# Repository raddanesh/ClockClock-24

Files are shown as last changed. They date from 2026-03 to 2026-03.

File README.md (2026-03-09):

# ClockClock-24

## LPC845-BRK usage in master and client firmware

This project uses the **NXP LPC845-BRK** as the main MCU platform for both firmware roles in the system. I kept a **single firmware codebase** and used compile-time configuration to switch the board behavior between **master** and **client** modes.

The [LPC845 breakout](https://www.nxp.com/design/design-center/development-boards-and-designs/LPC845-BRK) board provides a powerful and flexible development system for NXP's low end Cortex-M0+-based LPC84x Family of MCUs, delivered in an ultra-low-cost evaluation board. 

This breakout board can be used with a range of development tools, including the MCUXpresso IDE toolchain. The LPCXpresso845 Breakout board is developed by NXP to enable evaluation of and prototyping with the LPC84x family of MCUs.

<p align="center">
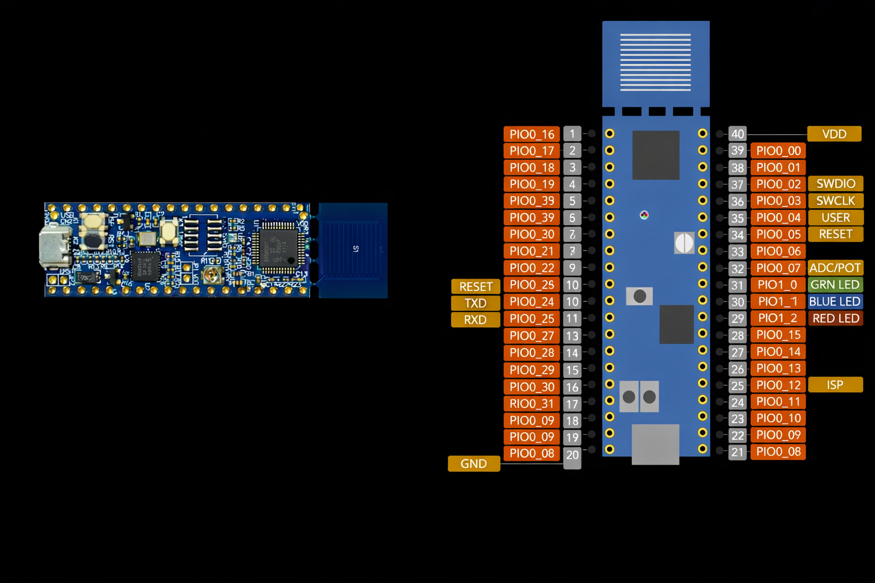
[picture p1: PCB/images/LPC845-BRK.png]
LPC845-BRK
  
</p>

The LPC845 breakout board features an on-board CMSIS-DAP debug and VCOM port, RGB user LEDs, capacitive touch button, user potentiometer and allows an easy prototyping experience with access to 38 LPC845 port pins.

The role selection is controlled through `PL_CONFIG_IS_MASTER` in `platform.h`:

- `PL_CONFIG_IS_MASTER = 1` builds the **master**
- `PL_CONFIG_IS_MASTER = 0` builds the **client**

This approach keeps the low-level platform code shared while allowing each build to enable only the modules needed for its role.

### Why LPC845-BRK

I used the LPC845-BRK because it provides the peripherals needed for this project in a compact Cortex-M0+ platform:

- enough GPIO for stepper-driver control lines and magnetic sensor inputs
- multiple USARTs for separating debug/shell communication from the RS-485 bus
- SCTimer support for motion timing
- internal flash for non-volatile configuration storage
- straightforward integration with the MCUXpresso SDK

The project follows the normal MCUXpresso startup flow:

- `BOARD_InitBootPins()`
- `BOARD_InitBootClocks()`
- `BOARD_InitBootPeripherals()`

After board startup, the firmware enters `APP_Run()`, initializes the platform in `PL_Init()`, and starts FreeRTOS.

### Shared LPC845 platform layer

Both master and client firmware use the same base initialization code in `platform.c`. In `PL_Init()`, the LPC845 initializes the shared system modules, including:

- MCU utility library
- FreeRTOS
- GPIO support
- optional shell/debug UART
- X12.017 stepper driver interface
- stepper control layer
- magnet sensor layer
- RS-485 communication
- non-volatile memory (`nvmc`)
- matrix logic

This gives both firmware roles the same hardware abstraction and startup flow, while feature selection is handled by configuration.

### LPC845-BRK in the master module

In **master mode**, the LPC845 is used as the **system coordinator**. Its job is not to drive the motors directly, but to manage the logical clock matrix and send commands to client boards.

The master firmware is responsible for:

- maintaining the logical matrix state
- converting digits and animations into hand target positions
- sending commands to client boards over **RS-485**
- providing a shell/debug interface over **USART0**

#### Master communication usage

On the master, I used:

- **USART0** for the local shell/debug console
- **USART2** for the RS-485 bus

This allows the master board to stay connected to a PC for debugging or manual commands while also controlling the distributed client nodes.

The shell is enabled only in master mode, so the LPC845 acts as both the local command interface and the RS-485 network controller.

#### Master logic role

The main master logic is implemented in `matrixMaster.c`. In this mode, the LPC845:

- stores the current matrix state
- maps clocks to board addresses and positions
- generates patterns for digits and animations
- forwards movement commands to the correct client board

So in the master build, the LPC845-BRK is mainly used as a **central controller and communication node**.

### LPC845-BRK in the client module

In **client mode**, the LPC845 is used as the **real-time motor-control MCU** for one physical board.

The client firmware is responsible for:

- controlling the local X12.017 driver ICs
- driving all local clock motors
- reading Hall/magnetic sensors for homing
- zeroing and calibrating the hands
- storing local calibration and address data in flash
- receiving commands from the master over **RS-485**

#### Client communication usage

On the client, the LPC845 uses **USART2** for RS-485 communication. Unlike the master, the client does not need the shell/debug console and focuses only on bus-controlled operation.

One useful LPC845 feature I used here is its **hardware-assisted RS-485 direction control**. Instead of manually toggling a GPIO for transmit/receive switching, the firmware uses the USART RTS output as the **RS485_TXRX_EN** signal.

In this design:

- `USART2_TXD` -> `P1_2`
- `USART2_RXD` -> `P1_0`
- `USART2_RTS` -> `P1_1`

This simplifies half-duplex RS-485 handling and reduces timing issues in the communication layer.

#### Client motion-control role

The client-side implementation is mainly in:

- `matrixClient.c`
- `stepper.c`
- `StepperBoard.c`

In this mode, the LPC845 directly controls the board hardware by:

- managing the local 12 motors
- generating step and direction signals for the X12.017 drivers
- using the **SCTimer** for motion timing
- reading magnet sensors to find repeatable zero positions
- applying stored offsets and backlash compensation

So in the client build, the LPC845-BRK is the actual **embedded motion-control node**.

### Internal flash usage

I also used the LPC845 internal flash to store persistent board-specific settings through the `nvmc` module. A reserved flash page is used for non-volatile configuration such as:

- RS-485 board address
- per-stepper zero offsets
- backlash compensation values

This allows each client board to keep its calibration and address after reset or power loss.

### Summary

The LPC845-BRK is used in two different roles in this project:

- In the **master**, it acts as the matrix controller, animation engine, shell host, and RS-485 command source.
- In the **client**, it acts as the real-time motor controller, handling X12.017 stepper driving, sensor-based homing, and local calibration storage.

Using the same LPC845 platform and shared codebase for both roles made the firmware easier to maintain while still allowing each build to specialize for its intended function.

<div align="center">
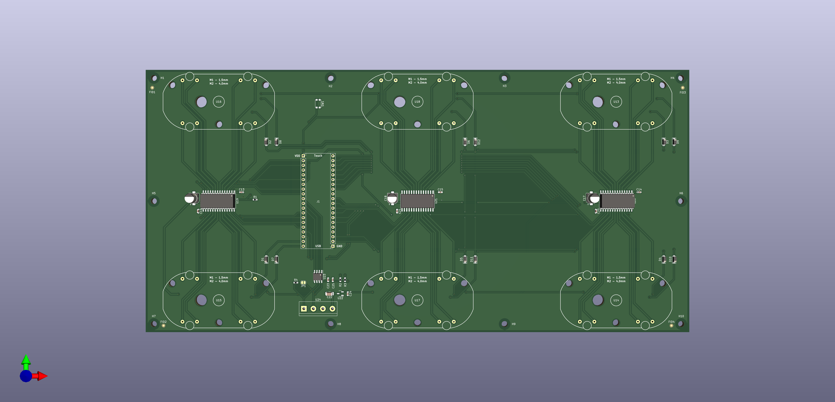
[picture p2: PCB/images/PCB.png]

</div>

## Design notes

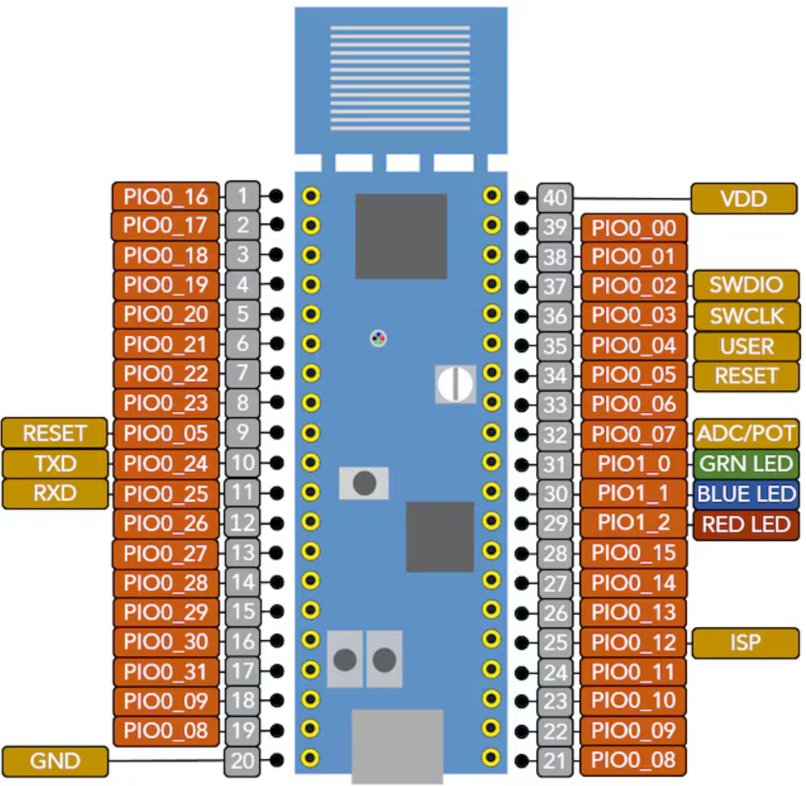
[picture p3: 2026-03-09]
PCB/images/LPC845-BRK-BD2.png

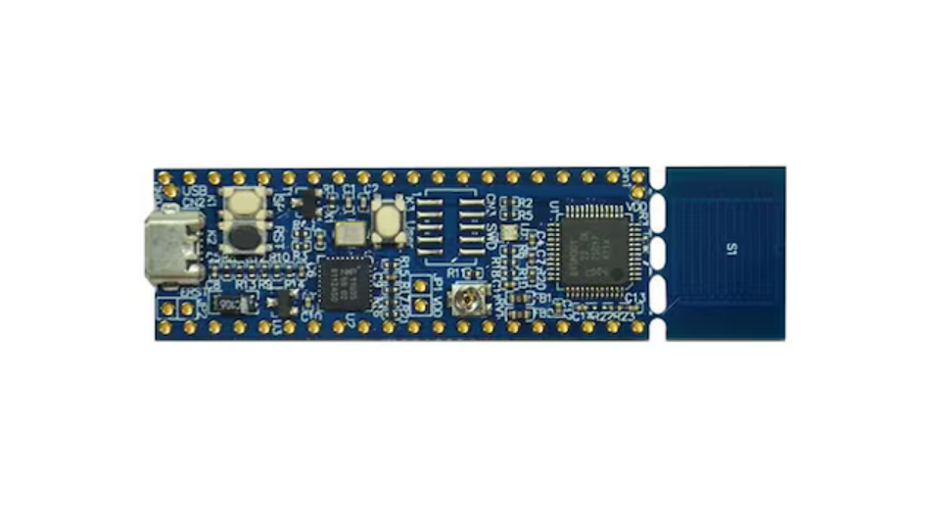
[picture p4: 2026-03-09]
PCB/images/LPC845-BRK-1.png

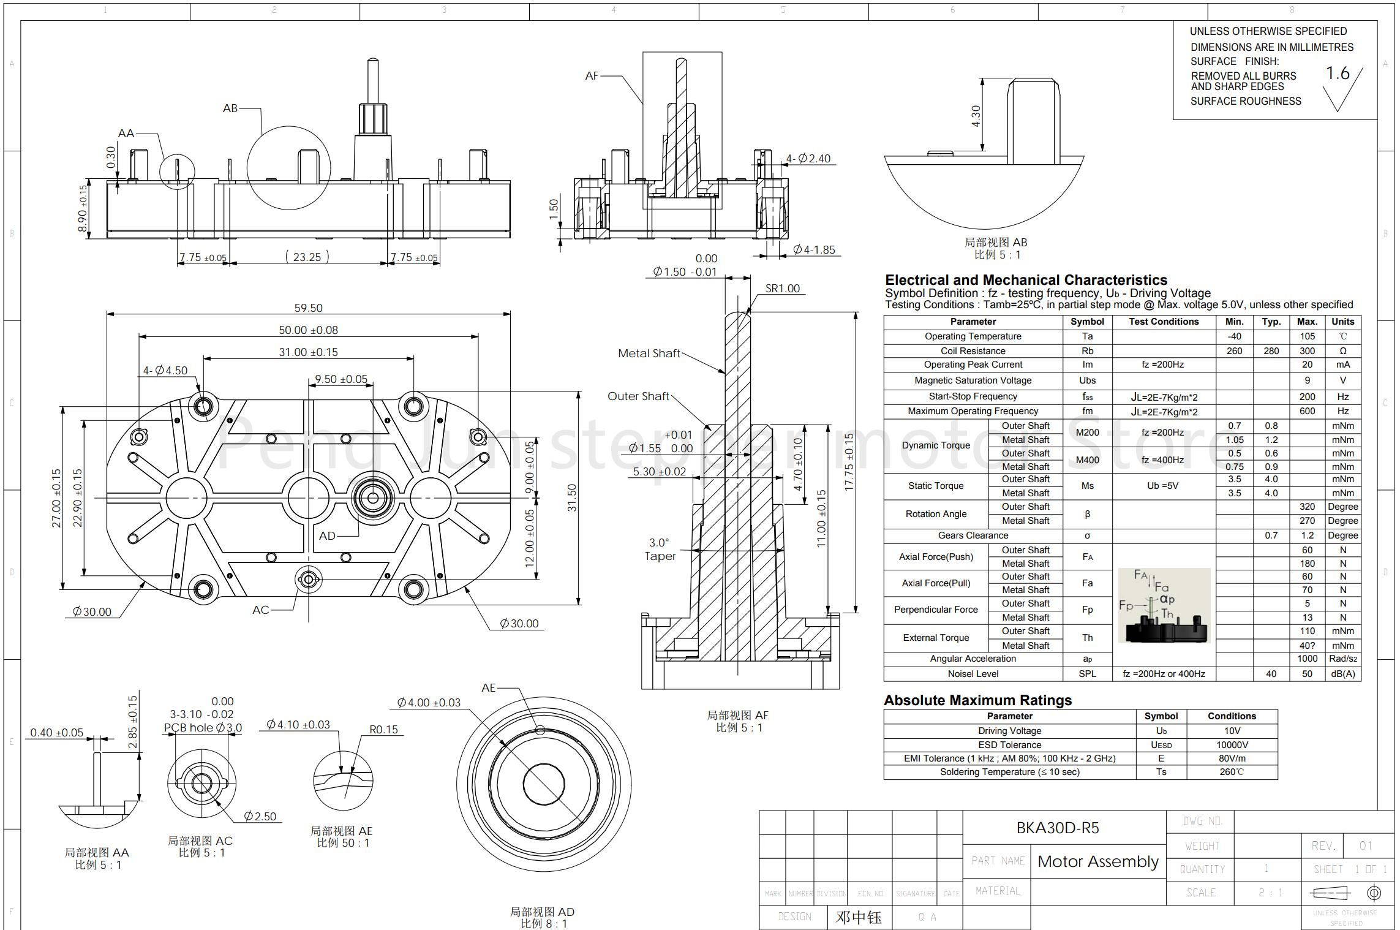
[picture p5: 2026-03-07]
PCB/BKA30D-R5/BKA30D-R5.jpg

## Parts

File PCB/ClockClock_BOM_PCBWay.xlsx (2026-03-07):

 |  |  | W520148AS1V2_PCS BOM (Bill of Materials)
Item # | *Ref Des | *Qty | Manufacturer | *Mfg Part # | Description / Value | *Package/Footprint | Type | Your Instructions / Notes | Source
1 | U19, U20, U21 | 3 | Switec | AX1201728SG | M-S Quad Driver X12.017 | SOL28 | SMD |  | Chip-IC Store: https://www.aliexpress.com/item/32596665175.html?spm=a2g0s.9042311.0.0.22e44c4d84lpPX
2 | U23 | 1 | Texas Instruments | SN65HVD75DR | SN65HVD75 | 8-Pin SOIC | SMD |  | Mouser #: 595-SN65HVD75DR
3 | U1, U2, U3, U4, U5, U6, U7, U8, U9, U10, U11, U12 | 12 | Diodes Incorporated | AH1913-W-7 | AH1913 | SC59-3 | SMD |  | Mouser #: 621-AH1913-W-7
4 | U22 | 1 | Torex Semiconductor | XC6206P332MR-G | XC6206-3.3V | SOT-23-3 | SMD |  | Mouser #: 865-XC6206P332MR-G
5 | U24 | 1 | TE Connectivity | 282836-2 | Fixed Terminal Blocks 5.0MM PCB MOUNT 2P | THT | thru-hole | Do not populate (DNP) | Mouser #: 571-2828362
6 | U13, U14, U15, U16, U17, U18 | 6 | Peng Chun Electronics | BKA30D-R5 360 degrees | VID28 Dual-Shaft Stepper Motor 360 degree | THT | thru-hole | Do not populate (DNP) | Pen Chung Electronics: https://www.aliexpress.com/item/32832881189.html?spm=a2g0s.9042311.0.0.22e44c4d84lpPX
7 | J1 | 1 | Harwin | M20-7822046 | LPC845-BRK socket | THT | thru-hole | Do not populate (DNP) | Mouser #: 855-M20-7822046
8 | C1, C2, C3, C4, C5, C6, C7, C8, C9, C10, C11, C12, C13, C14, C15, C19, C20, C21, C23 | 19 | ATC | 0603X7R104JT1AT | 100nF Ceramic, 25V | 0603 | SMD | Can be any ceramic 25V | Mouser #: 581-0603X7R104JT1AT
9 | C16, C17, C18 | 3 | Panasonic | EEE-1CA220SR | 22uF/16V Electrolyt | 5x5.5x5.4mm | SMD |  | Mouser #: 667-EEE-1CA220SR
10 | C24, C25 | 2 | Kemet | C0603C105K4PAC7411 | 1uF Ceramic, 16V | 0603 | SMD | Can be any ceramic 25V | Mouser #: 80-C0603C105K4PLR
11 | C22 | 1 | AVX | F9H1C106KAA | 10uF/16V Tantalum | 1206 | SMD | Can be any Tantalum >12V | Mouser #: 581-F9H1C106KAA
12 | R1, R2, R3 | 3 | Yageo | RT0603WRE0710KL | 10k Ohm 0.5% | 0603 | SMD | Can be any generic resistor 0.5% | Mouser #: 603-RT0603WRE0710KL
13 | R4 | 1 | Yageo | RT0603DRE07120RL | 120 Ohm 0.5% | 0603 | SMD | Can be any generic resistor 0.5% | Mouser #: 603-RT0603DRE07120RL
14 | D1, D2, D3, D4, D5, D6, D7, D8, D9, D10, D11, D12 | 12 | onsemi | MMSD4148T1G | General Purpose, Power, Switching 100V 200mA | SOD-123-2 | SMD |  | Mouser #: 863-MMSD4148T1G
15 | SW1 | 1 | C&K | KMR221GLFS | KMKR221G-LFS SPST Switch | 4.6x2.8x1.9mm | SMD |  | Mouser #: 611-KMR221G-LFS
Need a quick and accurante quote? Need an efficient production? Please read SMT Ordering Necessary Files & Info in 1 minute. Thank you very much! (https://www.pcbway.com/smt_ordering_guide.html)
Click for Instructions on How to Create a BOM (https://www.pcbway.com/blog/PCB_Assembly/How_to_Build_a_BOM__Bill_Of_Materials_.html)

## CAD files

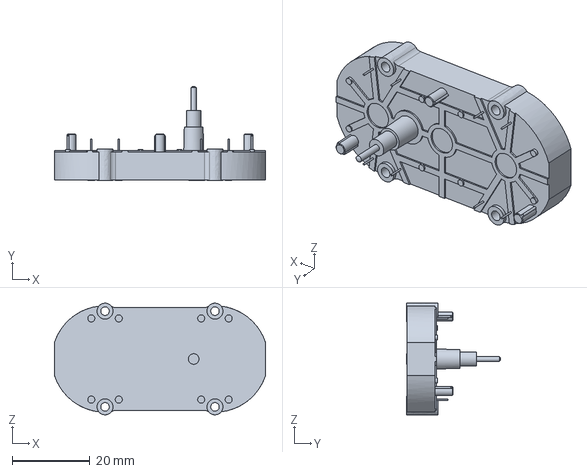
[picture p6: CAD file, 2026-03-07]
PCB/BKA30D-R5/Bka30D-R5.step
54.3 x 24.2 x 28.8 mm

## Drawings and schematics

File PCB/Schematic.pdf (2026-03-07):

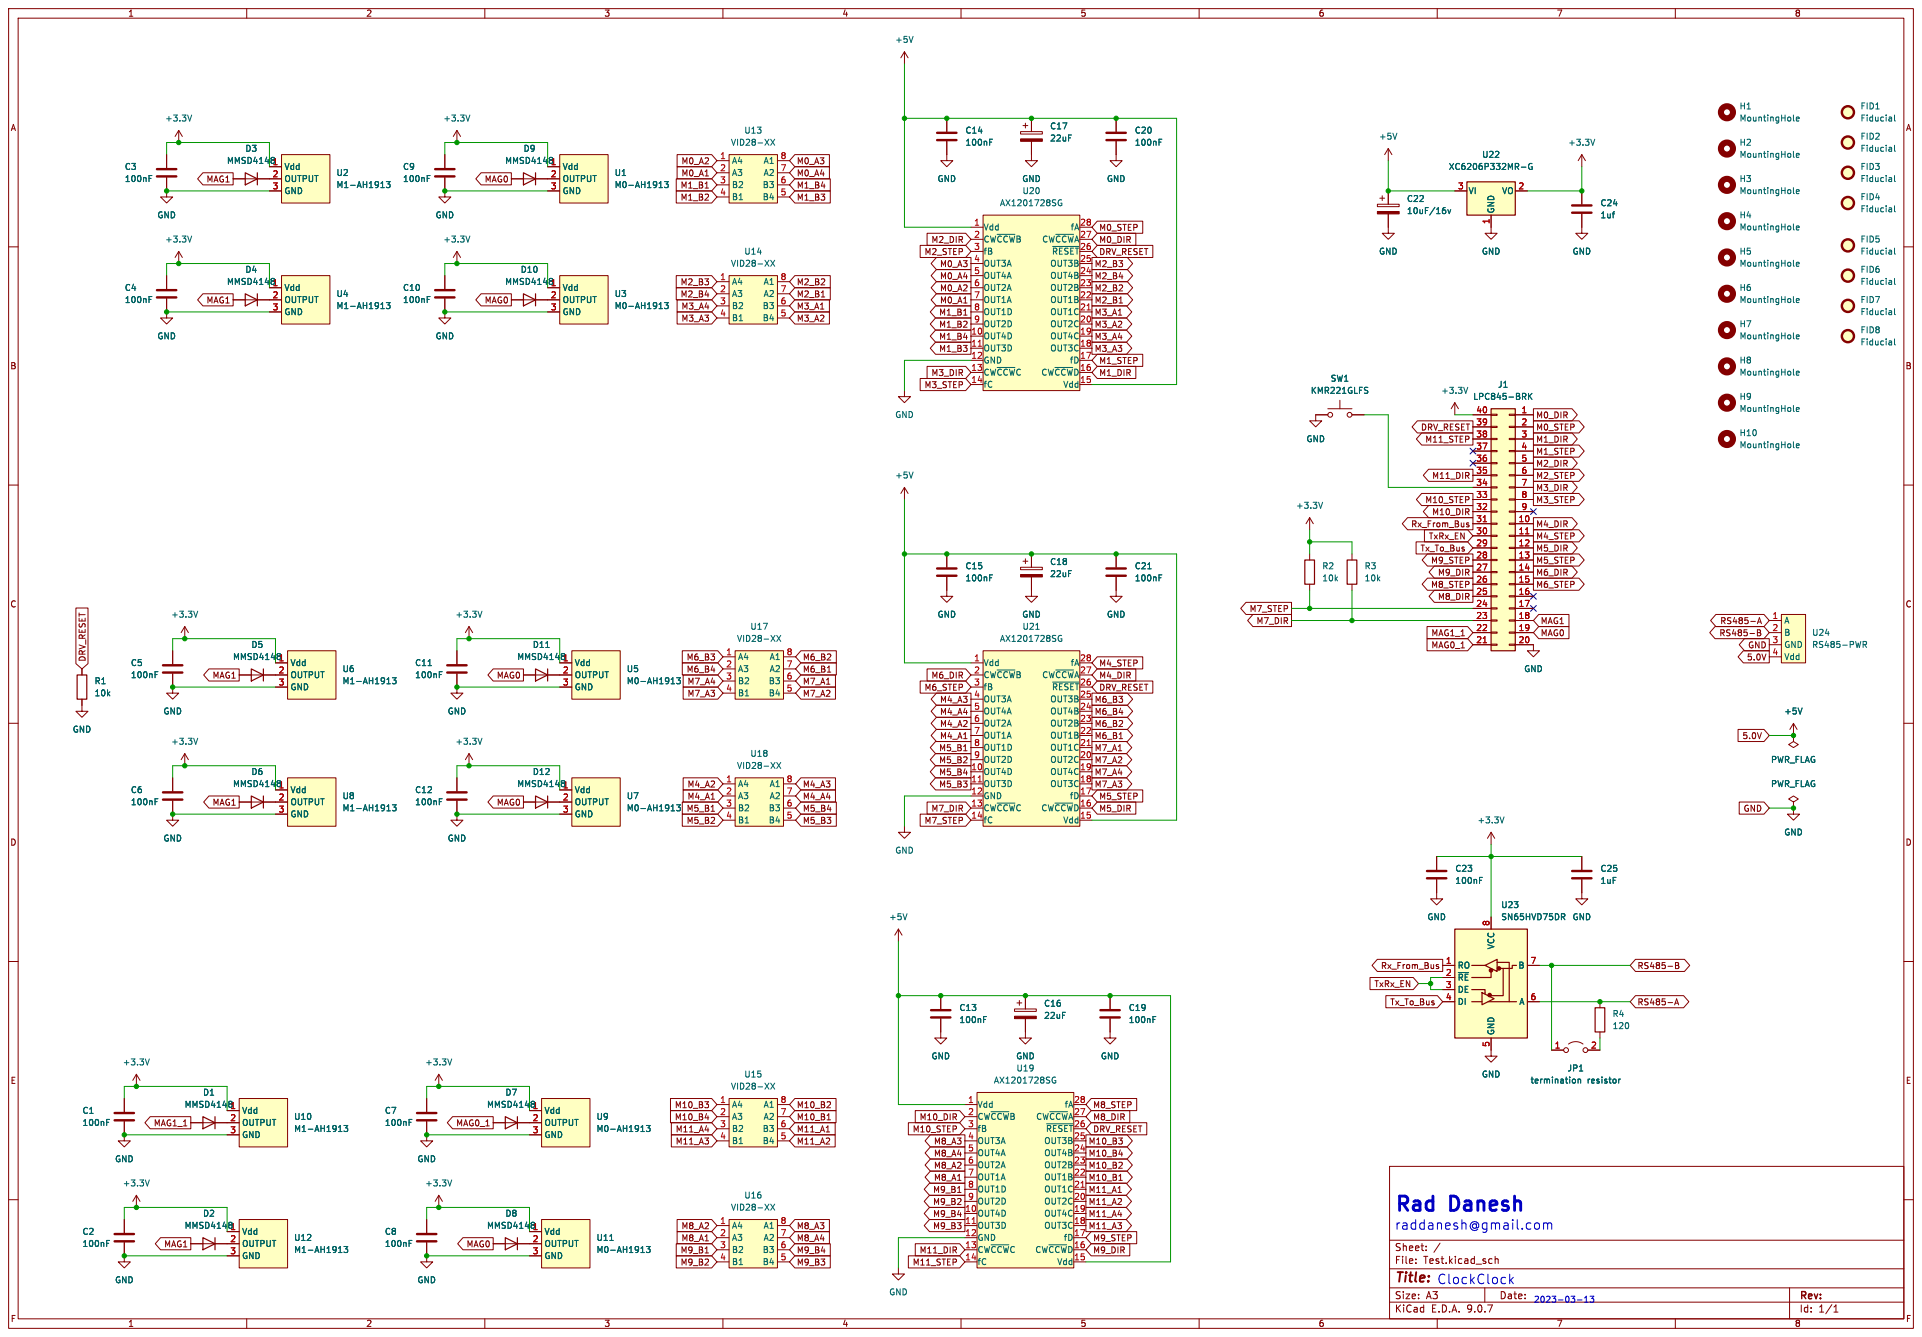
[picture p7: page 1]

fD 17 CW~{CCW}D16 Vdd 15 U20 AX1201728SG

FID2 Fiducial FID3 Fiducial FID7 Fiducial FID6 Fiducial GND

fA 28 CW~{CCW}A27 ~{RESET} 26 OUT3B 25 OUT4B 24 OUT2B 23 OUT1B 22 OUT1C 21 OUT2C 20 OUT4C 19 OUT3C 18

fB 3 OUT3A 4 OUT4A 5 OUT2A 6 OUT1A 7 OUT1D 8 OUT2D 9 OUT4D 10 OUT3D 11 GND 12 CW~{CCW}C 13

fD 17 CW~{CCW}D16 Vdd 15 U21 AX1201728SG

fD 17 CW~{CCW}D16 Vdd 15 U19 AX1201728SG

Id: 1/1 Title: File: Test.kicad_sch Sheet: /

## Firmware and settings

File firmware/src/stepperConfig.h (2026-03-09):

#ifndef STEPPERCONFIG_H_
#define STEPPERCONFIG_H_

#include "McuLibconfig.h"

#include "platform.h"
#define STEPPER_CONFIG_IS_LED_RING  (PL_CONFIG_USE_STEPPER_EMUL) /* temporary only */

#define STEPPER_CLOCK_360_STEPS   (4320) /* number of steps for 360 degrees */

/* time for a full round */
#define STEPPER_TIME_360_DEGREE_MS  (3000)
/* period needed for a single step in microseconds */
#define STEPPER_TIME_STEP_US        ((STEPPER_TIME_360_DEGREE_MS*1000U)/STEPPER_CLOCK_360_STEPS)
/* steps per second */
#define STEPPER_STEPS_PER_SEC							((STEPPER_CLOCK_360_STEPS*1000U)/STEPPER_TIME_360_DEGREE_MS)

#ifndef STEPPER_CONFIG_USE_FREERTOS_HEAP
  #define STEPPER_CONFIG_USE_FREERTOS_HEAP   (McuLib_CONFIG_SDK_USE_FREERTOS)
    /*!< 1: use FreeRTOS Heap (default), 0: use stdlib malloc() and free() */
#endif

#endif /* STEPPERCONFIG_H_ */

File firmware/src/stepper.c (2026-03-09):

#include "platform.h"
#include "stepperConfig.h"
#include "stepper.h"
#if PL_CONFIG_USE_X12_STEPPER
  #include "McuX12_017.h"
#endif
#if PL_CONFIG_USE_WDT
  #include "watchdog.h"
#endif
#include "McuRTOS.h"
#include "McuUtility.h"
#include "McuWait.h"
#include "Shell.h"
#include "matrix.h"
#include "fsl_ctimer.h"
#include "fsl_sctimer.h"
#include "StepperBoard.h"
#include "McuCriticalSection.h"

#define STEPPER_CMD_QUEUE_LENGTH    (8) /* maximum number of items in stepper command queue */
/* the degree of the move at the beginning and end which is used for acceleration and de-acceleration */
#define STEPPER_ACCELERATION_RANGE_DEGREE   (25)
#define STEPS_TO_DEGREE(steps)              (((steps)*360u)/STEPPER_CLOCK_360_STEPS)

#define STEPPER_START_TIMER()        SCTIMER_StartTimer(SCT0, kSCTIMER_Counter_U)
#define STEPPER_STOP_TIMER()         SCTIMER_StopTimer(SCT0, kSCTIMER_Counter_U)

typedef enum {
  SCT_CHANNEL_MASK_0 = (1<<0),
  SCT_CHANNEL_MASK_1 = (1<<1),
  SCT_CHANNEL_MASK_2 = (1<<2),
  SCT_CHANNEL_MASK_3 = (1<<3),
  SCT_CHANNEL_MASK_4 = (1<<4),
  SCT_CHANNEL_MASK_5 = (1<<5),
  SCT_CHANNEL_MASK_6 = (1<<6),
  SCT_CHANNEL_MASK_7 = (1<<7)
} SCT_CHANNEL_MASK_e;

/* default configuration, used for initializing the config */
static const STEPPER_Config_t defaultConfig =
{
  .device = NULL, /* motor or LED device */
  .stepFn = NULL, /* callback to increment or decrement steps */
  .getBacklashFn = NULL,
};

/* device for a single LED ring */
typedef struct {
  void *device; /* point to the actual motor device */
  void (*stepFn)(void *device, int step); /* function pointer to perform a single step forward (1) or backward (-1) */
  int32_t (*getBacklashFn)(void *device, Coord_t coord, int steps); /* function pointer to get backlash steps */
  int32_t lastBacklashMove;
  int32_t degree; /* current degree */
  int32_t pos; /* current position */
  int32_t doSteps; /* != 0: steps to do */
  int16_t delay; /* shortest delay: 0 */
  int16_t delayCntr; /* in the range of delay..0, step will be done at counter of 0 */
  int32_t accelStepCntr; /* current counter of steps since start */
  bool speedup, slowdown;
  Coord_t coord;
  QueueHandle_t queue; /* queue for the motor */
} STEPPER_Device_t;

void STEPPER_GetDefaultConfig(STEPPER_Config_t *config) {
  memcpy(config, &defaultConfig, sizeof(*config));
}

STEPPER_Handle_t STEPPER_DeinitDevice(STEPPER_Handle_t device) {
#if STEPPER_CONFIG_USE_FREERTOS_HEAP
  vPortFree(device);
#else
  free(device);
#endif
  return NULL;
}

STEPPER_Handle_t STEPPER_InitDevice(STEPPER_Config_t *config) {
  STEPPER_Device_t *handle;

#if STEPPER_CONFIG_USE_FREERTOS_HEAP
  handle = (STEPPER_Device_t*)pvPortMalloc(sizeof(STEPPER_Device_t)); /* get a new device descriptor */
#else
  handle = (STEPPER_Device_t*)malloc(sizeof(STEPPER_Device_t)); /* get a new device descriptor */
#endif
  assert(handle!=NULL);
  if (handle!=NULL) { /* if malloc failed, will return NULL pointer */
    memset(handle, 0, sizeof(STEPPER_Device_t)); /* init all fields */
    handle->device = config->device;
    handle->stepFn = config->stepFn;
    handle->getBacklashFn = config->getBacklashFn;
    handle->degree = 0;
    handle->pos = 0;
    handle->doSteps = 0;
    handle->delay = 0;
    handle->delayCntr = 0;
    handle->speedup = false;
    handle->slowdown = false;
    handle->coord = config->coord;
    handle->queue = xQueueCreate(STEPPER_CMD_QUEUE_LENGTH, sizeof(uint8_t*));
    if (handle->queue==NULL) {
      for(;;){} /* out of memory? */
    }
    vQueueAddToRegistry(handle->queue, "Squeue");
  }
  return handle;
}

void STEPPER_StopTimer(void) {
  STEPPER_STOP_TIMER();
}

void STEPPER_StartTimer(void) {
  STEPPER_START_TIMER();
}

#define STEP_SIZE  (1)

static void AccelDelay(STEPPER_Device_t *dev, int32_t degree) {
  /* this defines the acceleration/de-acceleration ramp depending on the step counter (at the beginning or at the end)
   * The delayCntr will be increased to have a slow start with a slow end.
   */
  if (degree<=STEPPER_ACCELERATION_RANGE_DEGREE) {
    if (degree<=2) {
      dev->delayCntr += 10;
    } else if (degree<=5) {
      dev->delayCntr += 7;
    } else if (degree<=10) {
      dev->delayCntr += 5;
    } else if (degree<=15) {
      dev->delayCntr += 3;
    } else if (degree<=STEPPER_ACCELERATION_RANGE_DEGREE) {
      dev->delayCntr += 1;
    }
  }
}

bool STEPPER_IsIdle(STEPPER_Handle_t stepper) {
  STEPPER_Device_t *mot = (STEPPER_Device_t*)stepper;
  return mot->doSteps==0;
}

bool STEPPER_TimerClockCallback(STEPPER_Handle_t stepper) {
  STEPPER_Device_t *mot = (STEPPER_Device_t*)stepper;
  int n;

  if (mot->doSteps==0) {
    return false; /* no work to do */
  }
  if (mot->delayCntr!=0) { /* delay going on? */
    mot->delayCntr -= STEP_SIZE; /* decrement delay counter */
    return true; /* still work go do */
  }
  /* do the step */
  if (mot->doSteps > 0) { /* forward */
    n = STEP_SIZE; /* number of steps in one iteration */
  } else { /* backward */
    n = -STEP_SIZE;
  }
  mot->pos += n; /* update position */
  if (mot->stepFn!=NULL) { /* call driver */
    mot->stepFn(mot->device, n);
  }
  mot->doSteps -= n; /* update remaining steps */
  mot->delayCntr = mot->delay*STEP_SIZE; /* reload delay counter */

  /* check if we have to speed up or slow down */
  if (mot->speedup || mot->slowdown) {
    int32_t stepsToGo; /* where we are in the sequence */

    stepsToGo = mot->doSteps;
    if (stepsToGo<0) { /* make it positive */
      stepsToGo = -stepsToGo;
    }
    if (mot->speedup && STEPS_TO_DEGREE(stepsToGo)>STEPPER_ACCELERATION_RANGE_DEGREE) { /* accelerate if we are starting up */
      if (STEPS_TO_DEGREE(mot->accelStepCntr)<=STEPPER_ACCELERATION_RANGE_DEGREE) {
        mot->accelStepCntr += STEP_SIZE; /* increase acceleration step counter position up to the cap value */
      }
      AccelDelay(mot, STEPS_TO_DEGREE(mot->accelStepCntr));
    } else if (mot->slowdown && STEPS_TO_DEGREE(stepsToGo)<STEPPER_ACCELERATION_RANGE_DEGREE) { /* slow down at the end */
      if (mot->accelStepCntr>=0) {
        mot->accelStepCntr -= STEP_SIZE; /* decrease the current de-accleration counter down to zero */
      }
      AccelDelay(mot, STEPS_TO_DEGREE(mot->accelStepCntr));
    }
  } /* speed up or slow down */
  return true; /* still work to do */
}

static void SCTIMER_Handler0(void) {
  uint32_t flags;

  flags = SCTIMER_GetStatusFlags(SCT0);
  if (flags & SCT_CHANNEL_MASK_0) {
    SCTIMER_ClearStatusFlags(SCT0, SCT_CHANNEL_MASK_0); /* Clear interrupt flag */
    MATRIX_TimerCallback();
  }
}
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

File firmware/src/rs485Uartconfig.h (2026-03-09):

#ifndef RS485UARTCONFIG_H_
#define RS485UARTCONFIG_H_

#include "fsl_usart.h"
#include "platform.h"

#define RS485Uart_CONFIG_USE_HW_OE_RTS  (1)  /* 1: Use e.g. on LPC845 OESEL (Output Enable Selection) feature. Note that the pin has to be configured in the PinMuxing as RTS! */

/* UART configuration items */
#define RS485Uart_CONFIG_UART_DEVICE                   USART2
#define RS485Uart_CONFIG_UART_SET_UART_CLOCK()         CLOCK_Select(kUART2_Clk_From_MainClk) /* Select the main clock as source clock of USART0. */
#define RS485Uart_CONFIG_UART_WRITE_BLOCKING           USART_WriteBlocking
#define RS485Uart_CONFIG_UART_GET_FLAGS                USART_GetStatusFlags
#define RS485Uart_CONFIG_UART_HW_RX_READY_FLAGS        (kUSART_RxReady|kUSART_HardwareOverrunFlag)
#define RS485Uart_CONFIG_UART_READ_BYTE                USART_ReadByte
#define RS485Uart_CONFIG_UART_CONFIG_STRUCT            usart_config_t
#define RS485Uart_CONFIG_UART_GET_DEFAULT_CONFIG       USART_GetDefaultConfig
#define RS485Uart_CONFIG_UART_ENABLE_INTERRUPTS        USART_EnableInterrupts
#define RS485Uart_CONFIG_UART_ENABLE_INTERRUPT_FLAGS   (kUSART_RxReadyInterruptEnable | kUSART_HardwareOverRunInterruptEnable)
#define RS485Uart_CONFIG_UART_IRQ_NUMBER               USART2_IRQn
#define RS485Uart_CONFIG_UART_INIT                     USART_Init
#define RS485Uart_CONFIG_UART_GET_CLOCK_FREQ_SELECT    kCLOCK_MainClk
#define RS485Uart_CONFIG_UART_IRQ_HANDLER              USART2_IRQHandler
#define RS485Uart_CONFIG_CLEAR_STATUS_FLAGS            USART_ClearStatusFlags

#if McuLib_CONFIG_CPU_IS_LPC  /* LPC845-BRK */
  #define RS485Uart_CONFIG_HAS_FIFO  (0)
#endif

#ifndef RS485Uart_CONFIG_UART_RX_QUEUE_LENGTH
  #if PL_CONFIG_IS_MASTER
    #define RS485Uart_CONFIG_UART_RX_QUEUE_LENGTH        (2*1024)
  #elif PL_CONFIG_IS_CLIENT
    #define RS485Uart_CONFIG_UART_RX_QUEUE_LENGTH        (128)
  #endif
  #define RS485Uart_CONFIG_UART_RESPONSE_QUEUE_LENGTH    (128)
#endif

#ifndef RS485Uart_CONFIG_UART_BAUDRATE
  #define RS485Uart_CONFIG_UART_BAUDRATE           115200
#endif

#endif /* RS485UARTCONFIG_H_ */

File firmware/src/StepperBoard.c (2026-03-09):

#include "StepperBoardConfig.h"
#include "StepperBoard.h"
#include "stepper.h"
#include <stddef.h>
#include <string.h>
#include <assert.h>
#if STEPBOARD_CONFIG_USE_FREERTOS_HEAP
  #include "McuRTOS.h"
#endif
#if PL_CONFIG_USE_WDT
  #include "watchdog.h"
#endif

typedef struct {
  uint8_t addr;
  bool enabled;
  STEPPER_Handle_t stepper[STEPBOARD_NOF_CLOCKS][STEPPER_NOF_CLOCK_MOTORS];
} STEPBOARD_Device_t;

/* default configuration, used for initializing the configuration */
static const STEPBOARD_Config_t defaultConfig =
{
  .addr = 0x0, .enabled = true,
  .stepper[0][0] = NULL, .stepper[0][1] = NULL,
  .stepper[1][0] = NULL, .stepper[1][1] = NULL,
  .stepper[2][0] = NULL, .stepper[2][1] = NULL,
  .stepper[3][0] = NULL, .stepper[3][1] = NULL,
	.stepper[4][0] = NULL, .stepper[4][1] = NULL,
	.stepper[5][0] = NULL, .stepper[5][1] = NULL,
};

void STEPBOARD_GetDefaultConfig(STEPBOARD_Config_t *config) {
  memcpy(config, &defaultConfig, sizeof(*config));
}

STEPBOARD_Handle_t STEPBOARD_InitDevice(STEPBOARD_Config_t *config) {
  STEPBOARD_Device_t *handle;

#if STEPBOARD_CONFIG_USE_FREERTOS_HEAP
  handle = (STEPBOARD_Device_t*)pvPortMalloc(sizeof(STEPBOARD_Device_t)); /* get a new device descriptor */
#else
  handle = (STEPBOARD_Device_t*)malloc(sizeof(STEPBOARD_Device_t)); /* get a new device descriptor */
#endif
  assert(handle!=NULL);
  if (handle!=NULL) { /* if malloc failed, will return NULL pointer */
    memset(handle, 0, sizeof(STEPBOARD_Device_t)); /* init all fields */
    handle->addr = config->addr;
    handle->enabled = config->enabled;
    handle->stepper[0][0] = config->stepper[0][0];
    handle->stepper[0][1] = config->stepper[0][1];
    handle->stepper[1][0] = config->stepper[1][0];
    handle->stepper[1][1] = config->stepper[1][1];
    handle->stepper[2][0] = config->stepper[2][0];
    handle->stepper[2][1] = config->stepper[2][1];
    handle->stepper[3][0] = config->stepper[3][0];
    handle->stepper[3][1] = config->stepper[3][1];
    handle->stepper[4][0] = config->stepper[4][0];
    handle->stepper[4][1] = config->stepper[4][1];
    handle->stepper[5][0] = config->stepper[5][0];
    handle->stepper[5][1] = config->stepper[5][1];
  }
  return handle;
}

uint8_t STEPBOARD_GetAddress(STEPBOARD_Handle_t board) {
  STEPBOARD_Device_t *handle = (STEPBOARD_Device_t*)board;
  return handle->addr;
}

bool STEPBOARD_IsEnabled(STEPBOARD_Handle_t board) {
  STEPBOARD_Device_t *handle = (STEPBOARD_Device_t*)board;
  return handle->enabled;
}

STEPPER_Handle_t STEPBOARD_GetStepper(STEPBOARD_Handle_t board, int clock, int motor) {
  STEPBOARD_Device_t *handle = (STEPBOARD_Device_t*)board;
  return handle->stepper[clock][motor];
}

bool STEPBOARD_ItemsInQueue(STEPBOARD_Handle_t board) {
  STEPBOARD_Device_t *handle = (STEPBOARD_Device_t*)board;
  QueueHandle_t queue;

  for(int i=0; i<STEPBOARD_NOF_CLOCKS; i++) {
    for(int j=0; j<STEPPER_NOF_CLOCK_MOTORS; j++) {
      queue = STEPPER_GetQueue(handle->stepper[i][j]);
      if (uxQueueMessagesWaiting(queue)!=0) { /* still things queued up? */
        return true; /* yes */
      }
    }
  }
  return false; /* nothing in queues */
}

bool STEPBOARD_IsIdle(STEPBOARD_Handle_t board) {
  STEPBOARD_Device_t *handle = (STEPBOARD_Device_t*)board;

  for(int i=0; i<STEPBOARD_NOF_CLOCKS; i++) {
    for(int j=0; j<STEPPER_NOF_CLOCK_MOTORS; j++) {
      if (!STEPPER_IsIdle(handle->stepper[i][j])) { /* still steps to do? */
        return false; /* yes, not finished */
      }
    }
  }
  return true; /* finished */
}

void STEPBOARD_NormalizePosition(STEPBOARD_Handle_t board) {
  STEPBOARD_Device_t *handle = (STEPBOARD_Device_t*)board;

  for(int i=0; i<STEPBOARD_NOF_CLOCKS; i++) {
    for(int j=0; j<STEPPER_NOF_CLOCK_MOTORS; j++) {
      STEPPER_NormalizePos(handle->stepper[i][j]);
    }
  }
}

void STEPBOARD_MoveAndWait(STEPBOARD_Handle_t board, uint32_t waitMs) {
  STEPPER_StartTimer();
  do {
    vTaskDelay(pdMS_TO_TICKS(waitMs));
#if PL_CONFIG_USE_WDT
    WDT_Report(WDT_REPORT_ID_CURR_TASK, waitMs);
#endif
  } while (!STEPBOARD_IsIdle(board));
}

STEPBOARD_Handle_t STEPBOARD_DeinitDevice(STEPBOARD_Handle_t device) {
#if STEPBOARD_CONFIG_USE_FREERTOS_HEAP
  vPortFree(device);
#else
  free(device);
#endif
  return NULL;
}

static STEPBOARD_Handle_t currBoard;
STEPBOARD_Handle_t STEPBOARD_GetBoard(void) {
  return currBoard;
}

void STEPBOARD_SetBoard(STEPBOARD_Handle_t board) {
  currBoard = board;
}

void STEPBOARD_Deinit(void) {
}

void STEPBOARD_Init(void) {
}

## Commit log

2026-03-07 Added PCB
    [ClockClock-B_Cu.gbl, ClockClock-B_Mask.gbs, ClockClock-B_Paste.gbp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]
2026-03-07 Added datasheets
    [Bka30D-R5.step]
